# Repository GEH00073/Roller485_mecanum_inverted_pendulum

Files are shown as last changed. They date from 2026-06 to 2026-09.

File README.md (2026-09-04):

# Roller485 Mecanum Inverted Pendulum

Roller485を4台と80 mmメカナムホイールを使った、横一列配置の倒立振子ロボットです。本体側ファームウェアとAtom JoyStickコントローラー側ファームウェアを1つのリポジトリにまとめています。

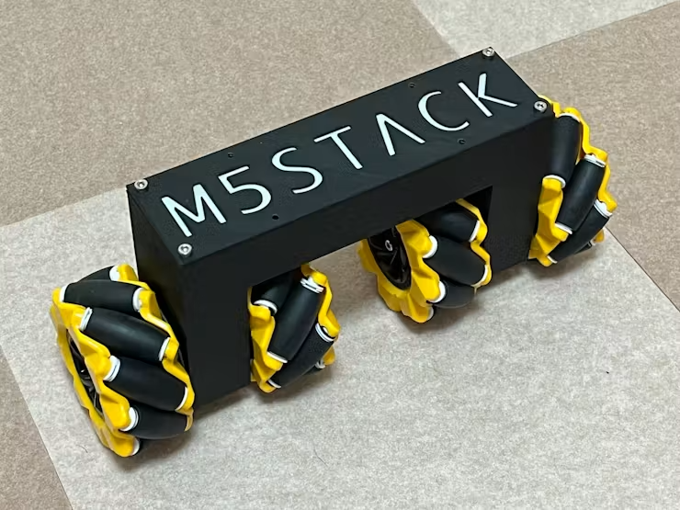
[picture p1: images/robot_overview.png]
完成したメカナムホイール倒立振子


[動作動画を見る](https://youtu.be/hXI0RIIv_HM)

## 構成

- 本体側: AtomS3R(またはAtomS3) + Roller485 x 4
- コントローラー側: Atom JoyStick
- 通信: ESP-NOW ch 3 ブロードキャスト
- 駆動電源: 7.2 V battery to PWR485
- 車輪: 80 mmメカナムホイール

## ディレクトリ構成

- `firmware/pendulum`: AtomS3R + Roller485 x 4 の本体側ファームウェア
- `firmware/controller`: Atom JoyStickコントローラー側ファームウェア
- `docs`: ESP-NOWパケット、配線、操作説明、安全注意の補足資料
- `images`: 写真や図を置くためのディレクトリ

## 起動から終了まで

1. コントローラーの電源を入れます。
2. 本体を安定した台に置き、4輪を床や台から浮かせます。
3. 倒立振子のバッテリーを接続します。
4. 4台のRoller485が1台ずつ順番に回転し、その後、ファームウェアの起動確認として4輪が同時に回転します。
5. `CHECK DONE` が表示され、車輪が停止するまで待ちます。
6. 車輪に触れない位置を持って本体を台から下ろし、床の上でできるだけ垂直に保持します。
7. 周囲の安全を確認して、コントローラーの右上ボタンを押し、倒立制御を開始します。
8. 終了時は本体が倒れないように保持してから右上ボタンを押します。
9. 車輪の停止を確認し、本体のバッテリーを必ず外します。
10. 最後にコントローラーの電源を切ります。

## コントローラー操作

| 操作動作 | 内容 |
| --- | --- |
| 右上ボタン | 倒立制御の開始／停止 |
| 左上ボタン | 通常モード／方向基準モードの切り替え |
| 右スティック上下 | 前進／後進 |
| 右スティック左右 | 左／右への平行移動 |
| 左スティック左右 | 左／右旋回 |
| 左スティック上下 | 前後ドリフトを抑えるための傾き補正 |

詳しい操作方法、方向基準モード、補正方法は [docs/controller.md](docs/controller.md) を参照してください。

## 安全上の注意

倒立振子は電源投入後や制御開始時に突然動く可能性があります。初回確認時は必ず車輪を浮かせ、周囲に十分な空間を確保してください。

- 初回確認時は必ず車輪を浮かせてテストしてください。
- 本体側は、有効なESP-NOWパケットを受信するまでモーターを起動しません。
- 本体ボタンだけでの単独起動は安全のため無効にしています。
- 転倒検出時とESP-NOW受信タイムアウト時はモーターを停止します。
- Roller485初期化に失敗した場合、制御タスクは開始されません。

## Roller485の配置とI2Cアドレス

4台のRoller485には、それぞれ異なるI2Cアドレスを設定します。

| 位置 | 説明 | I2Cアドレス |
| --- | --- | --- |
| LEFT | 左外側 | `0x64` |
| LEFT2 | 左内側 | `0x65` |
| RIGHT2 | 右内側 | `0x66` |
| RIGHT | 右外側 | `0x67` |

アドレスの変更方法とRoller485の電源仕様は、[M5Stack公式資料](https://docs.m5stack.com/ja/guide/motor_ctl/roller485/roller485)を参照してください。Roller485は1台ずつ接続して設定し、設定後はI2Cアドレスと取付位置が分かるラベルを貼ることを推奨します。

## ビルド方法

PlatformIOをインストールした環境で、それぞれのファームウェアディレクトリに移動してビルドします。リポジトリ直下ではなく、`firmware/pendulum` または `firmware/controller` をPlatformIOプロジェクトとして開いてください。

本体側ファームウェア:

```bash
cd firmware/pendulum
pio run
```

コントローラー側ファームウェア:

```bash
cd firmware/controller
pio run
```

初回ビルド時は、PlatformIOがボード定義や依存ライブラリを取得するため、インターネット接続が必要です。

## 機械加工・組立・3Dプリントについて

本機では、市販80 mmメカナムホイールの加工、3Dプリント部品、配線部品の現物合わせを行っています。3Dプリンター、材料、メカナムホイールの寸法公差、ネジ、コネクターなどにより、加工・組立条件は変わります。そのため、すべての環境に対応する詳細な組立手順やプリント条件を提示することは困難です。

STLとSTEPデータは [`3d_models`](3d_models) に収録しています。STEPデータも参考にし、使用する部品と製作環境に合わせて調整してください。

製作上の技術的な質問は、ほかの読者も回答を参照できるよう、原則として[GitHub Issues](https://github.com/GEH00073/Roller485_mecanum_inverted_pendulum/issues/new)を利用してください。質問には、使用部品の名称と型番、問題が発生している工程、配線または組立状態が分かる写真、表示されたメッセージや症状、使用したファームウェアのバージョンまたはコミットSHAを添えてください。

更新情報は [X @GEH00073](https://x.com/GEH00073) でも案内しますが、フォローやDMは必須ではありません。

## Roller485ライブラリについて

`unit_rolleri2c` は伊藤先生による修正版を使用しています。公式ライブラリより Roller485 との通信が速く、倒立振子のようにレスポンスが重要な用途では、この修正版を使用するのが適しています。

## OTA設定について

公開用の `platformio.ini` では、Wi-Fi SSIDとパスワードは空文字にしています。OTA書き込みを使う場合は、各自の環境に合わせて `WIFI_SSID`, `WIFI_PASSWORD`, 必要に応じて `OTA_PASSWORD` を設定してください。

## 関連ドキュメント

- `docs/espnow_packet.md`: ESP-NOWパケット仕様
- `docs/wiring.md`: AtomS3R、Roller485、電源まわりの配線
- `docs/controller.md`: Atom JoyStickコントローラーの操作説明
- `docs/safety.md`: 実験時の安全注意

## ライセンス

このリポジトリは複数ライセンスの集合であり、リポジトリ全体をMIT Licenseとするものではありません。個別ファイルの表示と[THIRD_PARTY_NOTICES.md](THIRD_PARTY_NOTICES.md)を優先してください。ライセンス原文は[LICENSES](LICENSES)にあります。

| 対象 | ライセンス／配布条件 | 備考 |
| --- | --- | --- |
| 伊藤恒平氏および片岡淳の独自コード（`firmware/*/src/main.cpp`、`firmware/controller/lib/ATOMS3Joy/`） | MIT | `LICENSES/MIT.txt`。伊藤氏の著作権を有する派生部分は、得たMIT条件の許諾に基づきます。 |
| M5Stack Unit Roller I2Cドライバーおよびbuzzer（`firmware/pendulum/src/unit_rolleri2c.*`、`firmware/controller/src/buzzer.*`） | MIT（M5Stack） | M5Stackのファイル内SPDX表示を保持しています。伊藤氏の高速化改変を含みます。 |
| MadgwickAHRS（`firmware/pendulum/src/MadgwickAHRS.*`） | GPL-3.0-only | Arduino版の上流が「GPL version 3」と明記しているためです。出典は第三者通知を参照してください。 |
| 本体側完成ファームウェア（`firmware/pendulum`） | GPL-3.0-only | MITの個別コードとGPL-3.0-onlyのMadgwickAHRSを結合してビルドするため、完成ファームウェアのソース／バイナリ配布にはGPL-3.0-onlyが適用されます。 |
| コントローラー側独自コード（`firmware/controller/src/`、`lib/ATOMS3Joy/`） | MIT | この行は独自コードだけを対象とします。 |
| コントローラー完成ファームウェア | MITの独自コード + M5Unified/M5GFX と各上流通知 | M5UnifiedはMIT。M5GFXはMITに加え、実際にリンクされるLovyanGFX・フォント・画像処理部の通知があります。GPL、LGPL、CC BY-SA 3.0 の旧M5AtomS3同梱物は含みません。詳細は`THIRD_PARTY_NOTICES.md`を参照してください。 |
| 文書、画像、3Dモデル（`docs/`、`images/`、`3d_models/`） | CC BY 4.0 | Copyright (c) 2026 Atsushi Kataoka。商用利用・再配布・改変を許可し、表示義務があります。`LICENSES/CC-BY-4.0.txt`を参照してください。 |

`LICENSE` はライセンス案内です。MITの原文だけをルートに置いて全ファイルへ適用されるように見せないため、この構成にしています。

```
Copyright (c) 2024 Kouhei Ito
Modifications Copyright (c) 2026 Atsushi Kataoka

Original code by Kouhei Ito. Modified by Atsushi Kataoka.
```

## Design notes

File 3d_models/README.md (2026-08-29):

# 3D model license

Copyright (c) 2026 Atsushi Kataoka

The 3D models in this directory, including STL and STEP files, are licensed
under Creative Commons Attribution 4.0 International (CC BY 4.0).  You may
share and adapt them, including for commercial purposes, if you provide
appropriate attribution and a link to the license.  See
`../LICENSES/CC-BY-4.0.txt`.

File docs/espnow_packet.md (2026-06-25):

# ESP-NOW パケット仕様

コントローラーは、チャンネル 3 で固定長 25 バイトの ESP-NOW ブロードキャストパケットを送信します。

```text
パケットサイズ: 25 バイト
byte 0-2: 宛先 MAC アドレス下位 3 バイト、またはブロードキャスト用の FF FF FF
byte 3-6: rudder / Psi、float
byte 7-10: throttle、float
byte 11-14: aileron / Phi、float
byte 15-18: elevator / Theta、float
byte 19: arm ボタン
byte 20: flip ボタン
byte 21: mode ボタン
byte 22: option ボタン
byte 23: proactive フラグ
byte 24: チェックサム、byte 0-23 の合計
```

現在公開しているファームウェアでは、byte 0-2 に `FF FF FF` を入れてブロードキャスト動作させています。本体側は、パケット長、宛先、チェックサムがすべて有効な場合だけ、最終受信時刻を更新します。

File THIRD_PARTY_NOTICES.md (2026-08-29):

# Third-party notices

This file records the licenses of third-party material included in this source
tree.  Retain this file and the referenced license texts when redistributing.

## MadgwickAHRS

`firmware/pendulum/src/MadgwickAHRS.cpp` and `.h` are derived from the Arduino
MadgwickAHRS library, itself an implementation of Sebastian Madgwick's AHRS
algorithm.  The upstream repository states GNU General Public License version
3: <https://github.com/arduino-libraries/MadgwickAHRS>.  This repository uses
the precise designation `GPL-3.0-only`; its text is
`LICENSES/GPL-3.0-only.txt`.  Atsushi Kataoka's modifications are identified in
the files.  The completed `firmware/pendulum` firmware must be distributed
under GPL-3.0-only.

## M5Stack Unit Roller I2C driver

`firmware/pendulum/src/unit_rolleri2c.cpp` and `.hpp` retain M5Stack Technology
CO LTD's `MIT` SPDX notices.  Upstream: <https://github.com/m5stack/M5Unit-Roller>.
The files include a performance-oriented I2C modification from the Kouhei Ito
derived project; do not remove M5Stack attribution.

`firmware/controller/src/buzzer.cpp` and `.h` also retain their M5Stack
Technology CO LTD MIT SPDX notices.

## Controller dependencies resolved by PlatformIO

The controller no longer vendors M5AtomS3.  Its `platformio.ini` resolves
M5Unified 0.2.21 and the transitive M5GFX 0.2.28 from the official M5Stack
PlatformIO packages.  The completed controller firmware therefore is not
described as “MIT only”: it contains the MIT-licensed project code together
with these dependencies and their applicable notices.

| Dependency actually linked in the clean build | Conditions | Upstream |
| --- | --- | --- |
| M5Unified 0.2.21 | MIT | <https://github.com/m5stack/M5Unified> |
| M5GFX 0.2.28 | M5GFX is MIT; the linked library also includes its documented LovyanGFX (FreeBSD), font, and image-code notices | <https://github.com/m5stack/M5GFX> |

The linker maps for both controller environments contain M5Unified and M5GFX,
and contain no M5AtomS3 or FastLED object.  M5GFX's upstream license inventory
lists the relevant component notices, including LovyanGFX (FreeBSD), Adafruit
GFX/GLCD fonts (2-clause BSD), Bodmer fonts (FreeBSD), IPA fonts (IPA Font
License), efont (3-clause BSD), TomThumb (3-clause BSD), and MIT-licensed image
utilities.  A distributor of a completed controller binary must retain the
notices from the exact M5Unified/M5GFX package versions used to build it.

The removed vendored M5AtomS3 library was the only repository material carrying
the former LGPL-2.1-or-later and CC BY-SA 3.0 notices.  Those licenses no
longer apply to this repository's controller source or its completed firmware.

## Documentation, images, and 3D models

`docs/`, `images/`, and `3d_models/` are Copyright (c) 2026 Atsushi Kataoka and
are licensed under Creative Commons Attribution 4.0 International (CC BY 4.0).
Commercial use, redistribution, and adaptation are permitted subject to the
attribution requirements.  The official license text is
`LICENSES/CC-BY-4.0.txt`; each directory contains a short notice.

## Project-origin code

For the MIT-licensed Kouhei Ito / Atsushi Kataoka code, retain:

```
Copyright (c) 2024 Kouhei Ito
Modifications Copyright (c) 2026 Atsushi Kataoka

Original code by Kouhei Ito. Modified by Atsushi Kataoka.
```

No license decision is made here for the repository's documentation, images,
or 3D models because their authorship and intended publication license are not
recorded in this tree.

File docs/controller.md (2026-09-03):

# コントローラー操作

Atom JoyStickコントローラーで倒立振子を操作します。起動時は通常モードです。

## 起動前の準備

1. コントローラーの電源を入れます。
2. 本体を安定した台に置き、4輪を床や台から浮かせます。
3. 周囲に人や障害物がなく、手、衣服、ケーブル、工具が車輪から離れていることを確認します。

## 起動手順

1. 本体のバッテリーを接続します。
2. 4台のRoller485が1台ずつ順番に回転することを確認します。
3. 続いて、ファームウェアの実装どおり4輪が同時に回転することを確認します。
4. `CHECK DONE` が表示され、車輪が停止するまで待ちます。
5. 本体を車輪や可動部から離れた位置で持ち、台から下ろして床の上でできるだけ垂直に保持します。
6. 周囲の安全を確認して右上ボタンを押し、倒立制御を開始します。

車輪が回転しない、回転方向が異常、異音がする、または引っ掛かりがある場合は、倒立制御を開始しないでください。本体のバッテリーを外して原因を確認してください。

## ボタンとスティックの割り当て

| 操作 | 動作 |
| --- | --- |
| 右上ボタン | 倒立制御を開始／停止します。 |
| 左上ボタン | 通常モードと方向基準モードを切り替えます。 |
| 右スティック上下 | 前進／後進します。 |
| 右スティック左右 | 左右へ平行移動します。 |
| 左スティック左右 | 左右旋回します。 |
| 左スティック上下 | 前後ドリフトを抑えるため、傾きの基準を補正します。 |

## 前後ドリフトの補正

前後へドリフトする場合は、左スティック上下で傾きの基準を補正します。左スティック上下は短く操作し、少しずつ調整してください。倒したままにすると補正が連続して変化するため注意してください。

## 移動方向モード

### 通常モード

起動時のモードです。本体の現在の向きを基準に、右スティックで前後・左右へ移動します。

### 方向基準モード

左上ボタンで方向基準モードへ切り替えると、その瞬間の本体の向きが基準方向として記憶されます。このモードでは本体が旋回しても、右スティックによる前後・左右移動は記憶した基準方向に対して行われます。

もう一度左上ボタンを押すと通常モードへ戻ります。基準方向を設定し直す場合は、一度通常モードへ戻し、希望する向きで再び左上ボタンを押してください。

## 終了手順

1. 本体が倒れないように保持します。
2. 右上ボタンを押して倒立制御を停止します。
3. 車輪が停止したことを確認し、本体のバッテリーを必ず外します。
4. バッテリーを外してからコントローラーの電源を切ります。

## 異常時の対応

異音、異常な回転、引っ掛かり、予期しない動作を感じた場合は、ただちに本体を安全に保持して倒立制御を停止してください。車輪の停止を確認してから本体のバッテリーを外し、原因を確認します。通電したまま無人で放置しないでください。

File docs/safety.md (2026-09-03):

# 安全上の注意

倒立振子は電源投入後や制御開始時に突然動く可能性があります。通電中はロボットの周囲に十分な空間を確保し、作業中は目を離さないでください。

## バッテリーと起動確認

- 損傷、変形、膨張、液漏れのあるバッテリーは使用しないでください。
- 本体を安定した台に置き、4輪を浮かせてからバッテリーを接続してください。
- 起動確認中は、手、衣服、ケーブル、工具を車輪へ近づけないでください。
- 起動確認が終了する前に、本体を台から持ち上げないでください。
- 回転しない車輪、異常な回転方向、異音、引っ掛かりがある場合は、倒立制御を開始せず、本体のバッテリーを外してください。

## 操作と終了

- 倒立制御を開始する前に、周囲の人と障害物を確認してください。
- 本体を持つ場合は、車輪や可動部から離れた位置を持ってください。
- 終了時は本体を保持してから右上ボタンで制御を停止してください。
- 車輪停止後に本体バッテリーを必ず外してください。
- バッテリーを外してからコントローラーを切ってください。
- 通電したまま無人で放置しないでください。

## ファームウェアの安全機能

- 電源投入直後に動き出さないよう、本体側は有効なESP-NOWパケットを受信するまでモーターを起動しません。
- ESP-NOWの受信タイムアウトを検出すると、モーターを停止します。
- 傾き角が転倒検出しきい値を超えると、モーターを停止します。
- Roller485の初期化に失敗した場合、制御タスクは開始されません。

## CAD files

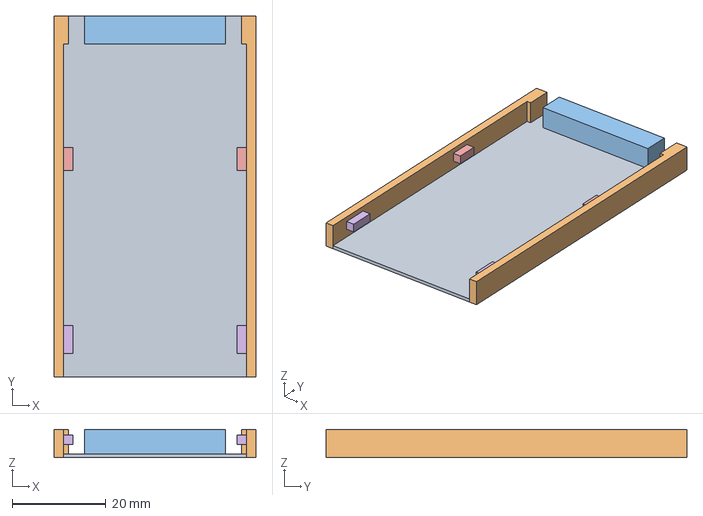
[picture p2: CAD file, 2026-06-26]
3d_models/STEP/NP-F550_batt_case.step
43.0 x 77.0 x 6.00 mm

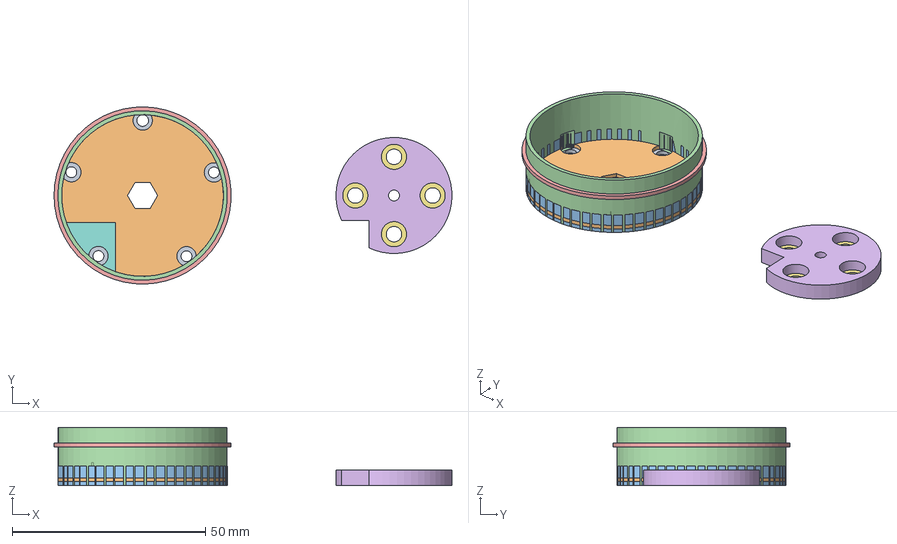
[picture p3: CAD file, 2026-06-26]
3d_models/STEP/80mm_mecanum_hub.step
102.9 x 45.8 x 15.0 mm

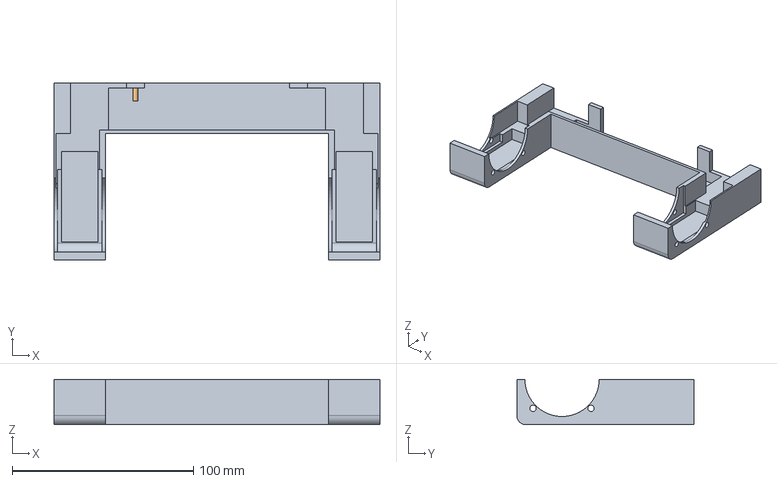
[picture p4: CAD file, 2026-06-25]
3d_models/STEP/roller485_mecanum_80mm_frame.step
180.0 x 98.0 x 25.0 mm

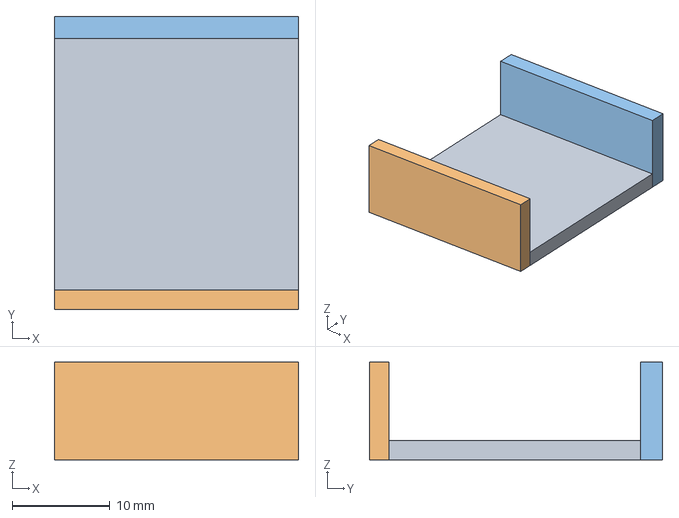
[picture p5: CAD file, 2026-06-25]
3d_models/STEP/atom_base.step
25.0 x 30.0 x 10.0 mm

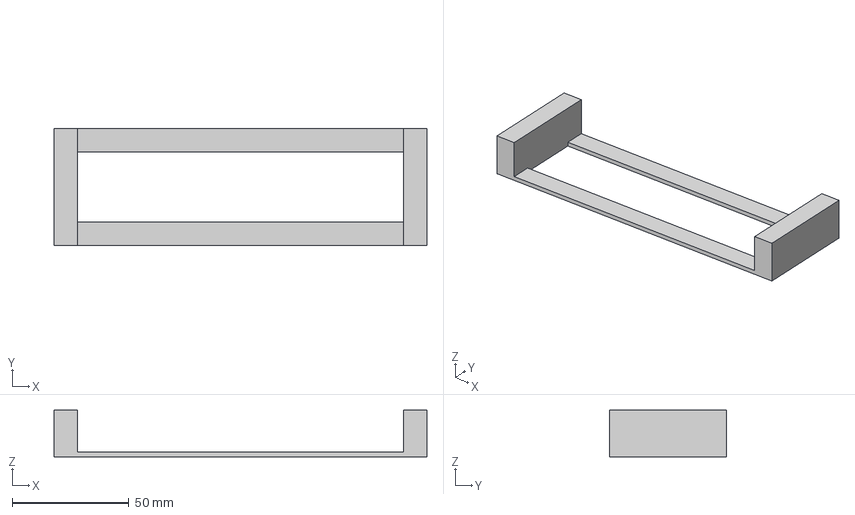
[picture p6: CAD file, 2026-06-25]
3d_models/STEP/80mm_mecanum_stand.step
160.0 x 50.0 x 20.0 mm

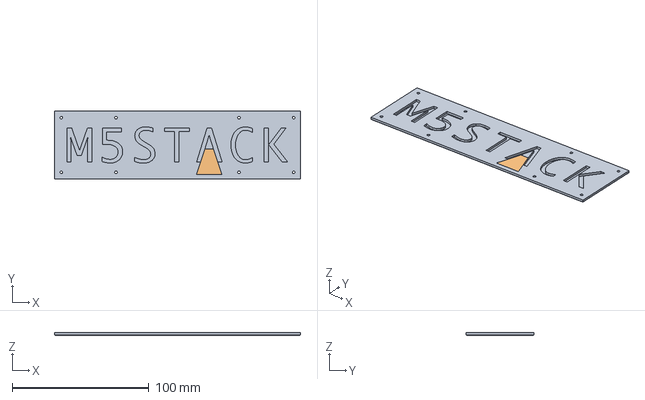
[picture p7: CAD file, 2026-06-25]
3d_models/STEP/80mm_mecanu_top_cover.step
180.0 x 50.0 x 2.00 mm

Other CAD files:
3d_models/STL/80mm_mecanu_top_cover.stl
3d_models/STL/80mm_mecanum_hub.stl
3d_models/STL/80mm_mecanum_stand.stl
3d_models/STL/NP-F550_batt_case.stl
3d_models/STL/atom_base.stl
3d_models/STL/roller485_mecanum_80mm_frame.stl

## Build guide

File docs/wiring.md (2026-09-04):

# 配線

トランジスタ技術の記事の接続図を前提にした配線です。配線作業中は必ずバッテリーを外してください。

## I2C信号

ATOMS3RまたはAtomS3のPORT.Aを使用します。G7、G8、GNDは4台のRoller485で共通にし、4台は同じI2Cバスを共有します。各Roller485はI2Cアドレスで識別します。

## ATOMS3R/AtomS3への5 V給電

ATOMS3R/AtomS3への5 Vは、4台のRoller485のうち任意の1台だけから供給します。複数のRoller485の5 V出力を並列接続しないでください。4台で共通にするのはG7、G8、GNDです。ATOMS3R/AtomS3へ5 Vを供給しない残り3台の5 V線は接続しません。

市販のGrove 4線ケーブルをそのまま4台分並列接続すると、5 V線まで並列接続される可能性があります。必要な信号線だけを接続できる自作ケーブルまたは分岐配線を使用してください。

## 7.2 V駆動電源

7.2 Vバッテリーを4台のRoller485のPWR485入力へ分配します。バッテリーのプラスを各PWR485電源入力へ、マイナスを各Roller485のGNDへ接続してください。ATOMS3R/AtomS3、Roller485、バッテリーのGNDは共通にします。

電源の極性を接続前に確認してください。逆接、短絡、配線抜けがある状態で電源を入れないでください。

Roller485の電源仕様とI2Cアドレス設定は、[M5Stack公式資料](https://docs.m5stack.com/ja/guide/motor_ctl/roller485/roller485)を参照してください。

## Roller485の配置とI2Cアドレス

| 位置 | 説明 | I2Cアドレス |
| --- | --- | --- |
| LEFT | 左外側 | `0x64` |
| LEFT2 | 左内側 | `0x65` |
| RIGHT2 | 右内側 | `0x66` |
| RIGHT | 右外側 | `0x67` |

アドレスの設定方法は、上記のM5Stack公式資料を参照してください。

## コントローラーとの通信

Atom JoyStick コントローラーと本体側 AtomS3R/AtomS3 は、ESP-NOW のチャンネル 3 で無線接続します。

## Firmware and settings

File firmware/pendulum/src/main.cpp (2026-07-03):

// SPDX-FileCopyrightText: 2024 Kouhei Ito
// SPDX-FileCopyrightText: 2026 Atsushi Kataoka
// SPDX-License-Identifier: MIT
//
// Experimental firmware for a mecanum-wheel inverted pendulum using four Roller485 units.
// The 5 ms control loop updates the IMU, estimates attitude, runs balance control, and
// distributes current commands to the four wheels.
// For first bring-up, always test with the wheels lifted off the floor.
// Motors are stopped on ESP-NOW receiver timeout or fall detection.
// Motors do not start until a valid ESP-NOW packet is received; local button-only
// startup is intentionally disabled for safety.

#include <Arduino.h>
#include <ArduinoOTA.h>
#include "unit_rolleri2c.hpp"
#include <M5Unified.h>
#include <MadgwickAHRS.h>
#include <WiFi.h>
#include <esp_now.h>
#include <esp_wifi.h>
#include <cstring>

// Roller layout reference:
//   LEFT   = left outer,  addr 0x64
//   LEFT2  = left inner,  addr 0x65
//   RIGHT2 = right inner, addr 0x66
//   RIGHT  = right outer, addr 0x67
UnitRollerI2C RollerI2C_RIGHT;  // Create a UNIT_ROLLERI2C object
UnitRollerI2C RollerI2C_RIGHT2;
UnitRollerI2C RollerI2C_LEFT;
UnitRollerI2C RollerI2C_LEFT2;
//I2Cドライバの多重初期化を防ぐためのフラグ
bool UnitRollerI2C::initialized = false;

float Pitch_ahrs, Roll_ahrs, Yaw_ahrs, Roll_bias, Roll;
float Gyro_x, Gyro_y, Gyro_z;
float Acc_x, Acc_y, Acc_z;
int32_t Imu_time,_Imu_time, Imu_dtime;
int32_t Current_ref_r, Current_ref_l;
int32_t Current_ref_r2, Current_ref_l2;
int32_t Current_r, Current_l;
int32_t Current_r2, Current_l2;
int32_t Pos_r, Pos_l, Pos_bias_r, Pos_bias_l;
int32_t Pos_r2, Pos_l2, Pos_bias_r2, Pos_bias_l2;
int32_t Speed_r, Speed_l;
int32_t Speed_r2, Speed_l2;
int32_t Voltage_r,Voltage_l;
int32_t Voltage_r2,Voltage_l2;
int32_t St, _St, Et, Dt;
float f1,f2,f3,f4;
float k1;
float U0, U_yaw, U_v, U_l;
uint8_t Start_flag = 0;
bool mode_flag = false;
float yaw, angle, start_yaw, target_yaw, diff;

#ifndef WIFI_SSID
#define WIFI_SSID ""
#endif

#ifndef WIFI_PASSWORD
#define WIFI_PASSWORD ""
#endif

#ifndef OTA_HOSTNAME
#define OTA_HOSTNAME "roller485-pendulum"
#endif

#ifndef OTA_PASSWORD
#define OTA_PASSWORD ""
#endif

namespace {
constexpr uint32_t kStartupOtaWindowMs = 5000;
constexpr int32_t kBatteryDetectVinRaw = 600;  // getVin() is displayed as raw / 100.0 V.
constexpr int32_t kStartupCheckCurrent = 10000;
constexpr uint32_t kStartupCheckPulseMs = 450;
constexpr uint32_t kStartupCheckSettleMs = 250;
constexpr uint32_t kControlPeriodMs = 5;
constexpr uint32_t kRcTimeoutMs = 300;
constexpr float kFallStopAngleDeg = 70.0f;
constexpr int32_t kCurrentLimit = 120000;
constexpr float kStickDeadband = 0.05f;
constexpr float kRollAngleGain = 7000.0f;
constexpr float kGyroGain = 250.0f;
constexpr float kWheelSpeedGain = -5.0f;
constexpr float kYawRateGain = 300.0f;
constexpr float kForwardGain = 150000.0f;
constexpr float kLateralGain = 100000.0f;
constexpr float kLateralYawCompensationGain = 67000.0f;
constexpr float kYawReferenceScale = -360.0f / 2.0f;
constexpr float kDriftTargetYawStep = 1.0f;
constexpr uint32_t kUiToggleDebounceMs = 500;
constexpr uint32_t kRollBiasAdjustIntervalMs = 100;
constexpr float kRollBiasStepDeg = 0.2f;
constexpr uint8_t kEspNowChannel = 3;
constexpr uint8_t kBroadcastAddr[6] = {0xff, 0xff, 0xff, 0xff, 0xff, 0xff};
bool startupOtaStarted = false;
bool startupOtaInProgress = false;
volatile uint8_t MyMacAddr[6];
volatile uint8_t Rc_err_flag = 0;
volatile uint8_t Recv_MAC[3];
volatile uint16_t Connect_flag = 0;
volatile float Stick[16];
volatile uint32_t last_rc_rx_ms = 0;
portMUX_TYPE stickMux = portMUX_INITIALIZER_UNLOCKED;
esp_now_peer_info_t peerInfo;

enum StickIndex : uint8_t {
    RUDDER = 0,
    ELEVATOR = 1,
    THROTTLE = 2,
    AILERON = 3,
    LOG = 4,
    BUTTON_ARM = 9,
    BUTTON_FLIP = 10,
    CONTROLMODE = 11,
    ALTCONTROLMODE = 12,
};

void copyStickSnapshot(float (&snapshot)[16])
{
    portENTER_CRITICAL(&stickMux);
    for (uint8_t i = 0; i < 16; i++) {
        snapshot[i] = Stick[i];
    }
    portEXIT_CRITICAL(&stickMux);
}

uint32_t getLastRcRxMs()
{
    portENTER_CRITICAL(&stickMux);
    const uint32_t lastRxMs = last_rc_rx_ms;
    portEXIT_CRITICAL(&stickMux);
    return lastRxMs;
}

float readFloatFromPacket(const uint8_t* recvData, uint8_t offset)
{
    float value = 0.0f;
    memcpy(&value, &recvData[offset], sizeof(value));
    return value;
}

int32_t clampCurrent(int32_t current)
{
    if (current > kCurrentLimit) {
        return kCurrentLimit;
    }
    if (current < -kCurrentLimit) {
        return -kCurrentLimit;
    }
    return current;
}

struct StartupRollerCheckStep {
    const char* label;
    uint8_t addr;
    UnitRollerI2C* roller;
    int8_t logicalSign;
};

bool startupOtaIsConfigured()
{
    return strlen(WIFI_SSID) > 0;
}

void onEspNowRecv(const uint8_t* macAddr, const uint8_t* recvData, int dataLen)
{
    (void)macAddr;
    Connect_flag = 0;

    if (dataLen < 25) {
        Rc_err_flag = 1;
        return;
    }

    Recv_MAC[0] = recvData[0];
    Recv_MAC[1] = recvData[1];
    Recv_MAC[2] = recvData[2];

    const bool addressedToMe =
        (recvData[0] == MyMacAddr[3]) && (recvData[1] == MyMacAddr[4]) && (recvData[2] == MyMacAddr[5]);
    const bool addressedToBroadcast =
        (recvData[0] == 0xff) && (recvData[1] == 0xff) && (recvData[2] == 0xff);

    if (!addressedToMe && !addressedToBroadcast) {
        Rc_err_flag = 1;
        return;
    }

    uint8_t checkSum = 0;
    for (uint8_t i = 0; i < 24; i++) {
        checkSum = checkSum + recvData[i];
    }
    if (checkSum != recvData[24]) {
        Rc_err_flag = 1;
        return;
    }

    Rc_err_flag = 0;

    const float rudder = readFloatFromPacket(recvData, 3);
    const float throttle = readFloatFromPacket(recvData, 7);
    const float aileron = readFloatFromPacket(recvData, 11);
    const float elevator = readFloatFromPacket(recvData, 15);
    const uint32_t nowMs = millis();

    portENTER_CRITICAL(&stickMux);
    Stick[RUDDER] = rudder;
    Stick[THROTTLE] = throttle;
    Stick[AILERON] = aileron;
    Stick[ELEVATOR] = elevator;
    Stick[BUTTON_ARM] = recvData[19];
    Stick[BUTTON_FLIP] = recvData[20];
    Stick[CONTROLMODE] = recvData[21];
    Stick[ALTCONTROLMODE] = recvData[22];
    Stick[LOG] = 0.0f;
    last_rc_rx_ms = nowMs;
    portEXIT_CRITICAL(&stickMux);
}

void rcInit()
{
    portENTER_CRITICAL(&stickMux);
    for (uint8_t i = 0; i < 16; i++) {
        Stick[i] = 0.0f;
    }
    last_rc_rx_ms = 0;
    portEXIT_CRITICAL(&stickMux);

    WiFi.mode(WIFI_STA);
    WiFi.disconnect();

    WiFi.macAddress((uint8_t*)MyMacAddr);
    Serial.printf("MAC ADDRESS: %02X:%02X:%02X:%02X:%02X:%02X\r\n",
                  MyMacAddr[0], MyMacAddr[1], MyMacAddr[2],
                  MyMacAddr[3], MyMacAddr[4], MyMacAddr[5]);

    if (esp_now_init() != ESP_OK) {
        Serial.println("ESPNow Init Failed");
        ESP.restart();
    }
    Serial.println("ESPNow Init Success");

    esp_wifi_set_channel(kEspNowChannel, WIFI_SECOND_CHAN_NONE);

    memset(&peerInfo, 0, sizeof(peerInfo));
    memcpy(peerInfo.peer_addr, kBroadcastAddr, 6);
    peerInfo.channel = kEspNowChannel;
    peerInfo.encrypt = false;
    if (esp_now_add_peer(&peerInfo) != ESP_OK) {
        Serial.println("Failed to add broadcast peer");
        return;
    }

    esp_now_register_recv_cb(onEspNowRecv);
    Serial.println("ESP-NOW Broadcast Ready.");
}

void setupStartupOTA()
{
    if (startupOtaStarted || !startupOtaIsConfigured()) {
        return;
    }

    ArduinoOTA.setHostname(OTA_HOSTNAME);
    if (strlen(OTA_PASSWORD) > 0) {
        ArduinoOTA.setPassword(OTA_PASSWORD);
    }

    ArduinoOTA
        .onStart([]() {
            startupOtaInProgress = true;
            Start_flag = 0;
            Serial.println("OTA update started during startup window.");
            M5.Display.clear(TFT_BLUE);
            M5.Display.setCursor(0, 10);
            M5.Display.print("OTA");
        })
        .onEnd([]() {
            Serial.println("\nOTA update finished. Restarting.");
            delay(500);
            ESP.restart();
        })
        .onProgress([](unsigned int progress, unsigned int total) {
            const unsigned int percent = total == 0 ? 0 : (progress * 100) / total;
            static unsigned int lastPercent = 101;
            if (percent != lastPercent) {
                lastPercent = percent;
                Serial.printf("OTA progress: %u%%\r", percent);
            }
        })
        .onError([](ota_error_t error) {
            startupOtaInProgress = false;
            Serial.printf("OTA error[%u]\n", error);
        });

    ArduinoOTA.begin();
    startupOtaStarted = true;
    Serial.printf("Startup OTA ready: %s.local IP: %s\n", OTA_HOSTNAME, WiFi.localIP().toString().c_str());
}

void updateImuDuringStartupOTA()
{
    M5.Imu.update();
    auto imudata = M5.Imu.getImuData();
    Gyro_x = imudata.gyro.x;
    Gyro_y = imudata.gyro.y;
    Gyro_z = imudata.gyro.z;
    Acc_x = imudata.accel.x;
    Acc_y = imudata.accel.y;
    Acc_z = imudata.accel.z;
    MadgwickAHRSupdateIMU(Gyro_x * DEG_TO_RAD, Gyro_y * DEG_TO_RAD, Gyro_z * DEG_TO_RAD, Acc_x, Acc_y, Acc_z, &Pitch_ahrs, &Roll_ahrs, &Yaw_ahrs);
    Roll = 0.3f * Roll + 0.7f * Roll_ahrs;
}

void serviceStartupOTAWindow()
{
    if (!startupOtaIsConfigured()) {
        return;
    }

    const uint32_t windowStartMs = millis();
    WiFi.mode(WIFI_STA);
    WiFi.begin(WIFI_SSID, WIFI_PASSWORD);
    Serial.printf("Startup OTA + IMU calibration window: connecting WiFi %s\n", WIFI_SSID);
    M5.Display.clear(TFT_BLUE);
    M5.Display.setCursor(0, 10);
    M5.Display.print("OTA+IMU");

    while ((millis() - windowStartMs < kStartupOtaWindowMs) || startupOtaInProgress) {
        updateImuDuringStartupOTA();
        if (WiFi.status() == WL_CONNECTED) {
            setupStartupOTA();
            ArduinoOTA.handle();
        }
        M5.update();
        delay(10);
    }

    if (startupOtaStarted) {
        ArduinoOTA.end();
        startupOtaStarted = false;
    }
    WiFi.disconnect(false, true);
    WiFi.mode(WIFI_OFF);
    M5.Display.clear(TFT_BLACK);
    Serial.println("Startup OTA window closed. Continuing normal startup.");
}

void stopAllRollers()
{
    Current_ref_r = 0;
    Current_ref_l = 0;
    Current_ref_r2 = 0;
    Current_ref_l2 = 0;
    RollerI2C_RIGHT.setCurrent(0);
    RollerI2C_LEFT.setCurrent(0);
    RollerI2C_RIGHT2.setCurrent(0);
    RollerI2C_LEFT2.setCurrent(0);
}

void stopInitializedRollers(bool rightOk, bool leftOk, bool right2Ok, bool left2Ok)
{
    Current_ref_r = 0;
    Current_ref_l = 0;
    Current_ref_r2 = 0;
    Current_ref_l2 = 0;
    if (rightOk) {
        RollerI2C_RIGHT.setCurrent(0);
    }
    if (leftOk) {
        RollerI2C_LEFT.setCurrent(0);
    }
    if (right2Ok) {
        RollerI2C_RIGHT2.setCurrent(0);
    }
    if (left2Ok) {
        RollerI2C_LEFT2.setCurrent(0);
    }
}

void waitWithM5Update(uint32_t waitMs)
{
    const uint32_t startMs = millis();
    while (millis() - startMs < waitMs) {
        M5.update();
        delay(10);
    }
}

int32_t readStartupBatteryVinRaw()
{
    int32_t vin = RollerI2C_RIGHT.getVin();
    vin = max(vin, RollerI2C_LEFT.getVin());
    vin = max(vin, RollerI2C_RIGHT2.getVin());
    vin = max(vin, RollerI2C_LEFT2.getVin());
    return vin;
}

void applyLogicalCurrent(const StartupRollerCheckStep& step, int32_t current)
{
    step.roller->setCurrent(step.logicalSign * current);
}

void showStartupCheckScreen(const char* label, uint8_t addr, int32_t vinRaw)
{
    M5.Display.clear(TFT_BLACK);
    M5.Display.setCursor(0, 4);
    M5.Display.printf("CHK %s\n", label);
    M5.Display.printf("addr 0x%02X\n", addr);
    M5.Display.printf("Vin %4.1fV\n", (float)vinRaw / 100.0f);
}

void runStartupRollerCheckMode()
{
    const int32_t vinRaw = readStartupBatteryVinRaw();
    if (vinRaw < kBatteryDetectVinRaw) {
        Serial.printf("Startup roller check skipped. Vin %.2f V\n", (float)vinRaw / 100.0f);
        return;
    }

    const StartupRollerCheckStep steps[] = {
        {"LEFT",   0x64, &RollerI2C_LEFT,   -1},
        {"LEFT2",  0x65, &RollerI2C_LEFT2,   1},
        {"RIGHT2", 0x66, &RollerI2C_RIGHT2, -1},
        {"RIGHT",  0x67, &RollerI2C_RIGHT,   1},
    };

    Serial.printf("Startup roller check started. Vin %.2f V\n", (float)vinRaw / 100.0f);
    M5.Display.clear(TFT_BLUE);
    M5.Display.setCursor(0, 4);
    M5.Display.println("ROLLER CHECK");
    M5.Display.printf("Vin %4.1fV\n", (float)vinRaw / 100.0f);
    waitWithM5Update(800);

    stopAllRollers();
    for (const auto& step : steps) {
        showStartupCheckScreen(step.label, step.addr, vinRaw);
        Serial.printf("Check %s addr=0x%02X logical current=%ld raw current=%ld\n",
                      step.label,
                      step.addr,
                      (long)kStartupCheckCurrent,
                      (long)(step.logicalSign * kStartupCheckCurrent));
        applyLogicalCurrent(step, kStartupCheckCurrent);
        waitWithM5Update(kStartupCheckPulseMs);
        stopAllRollers();
        waitWithM5Update(kStartupCheckSettleMs);
    }

    M5.Display.clear(TFT_BLUE);
    M5.Display.setCursor(0, 4);
    M5.Display.println("CHK FWD");
    M5.Display.println("all wheels");
    Serial.println("Check all wheels logical forward");
    for (const auto& step : steps) {
        applyLogicalCurrent(step, kStartupCheckCurrent);
    }
    waitWithM5Update(kStartupCheckPulseMs);
    stopAllRollers();
    waitWithM5Update(kStartupCheckSettleMs);

    M5.Display.clear(TFT_BLACK);
    M5.Display.setCursor(0, 4);
    M5.Display.println("CHECK DONE");
    Serial.println("Startup roller check finished.");
    waitWithM5Update(500);
    M5.Display.clear(TFT_BLACK);
}
}  // namespace

void uiTask(void *pvParameters) {
    uint32_t lastStartToggleMs = 0;
    uint32_t lastModeToggleMs = 0;
    uint32_t lastRollBiasAdjustMs = 0;

    while (true) {
        vTaskDelay(pdMS_TO_TICKS(50));
        float stick[16];
        copyStickSnapshot(stick);
        const uint32_t nowMs = millis();

        M5.Display.setCursor(0, 10);
        M5.Display.printf("roll %4.1f\n", Roll);
        M5.Display.printf("V    %4.1f\n", (float)Voltage_r/100.0);
        M5.Display.printf("dt   %4.1f\n", (float)Dt/1.0e3);
        M5.Display.printf("yaw  %4.1f\n", (float)target_yaw);
        M5.Display.printf("diff %4.1f\n", (float)diff);

        M5.update();
        if((stick[CONTROLMODE] > 0.9 || M5.BtnA.wasPressed()) &&
           (nowMs - lastStartToggleMs >= kUiToggleDebounceMs)){ //右ボタンでトグル
            //Star_flagをトグル 
            Start_flag = !Start_flag;
            Roll_bias = Roll;
            Pos_bias_r = Pos_r;
            Pos_bias_l = Pos_l;
            start_yaw = -Yaw_ahrs;
            target_yaw = 0; 
            lastStartToggleMs = nowMs;
        }

        f4 = kWheelSpeedGain;

        if(stick[ALTCONTROLMODE] > 0.9 &&
           (nowMs - lastModeToggleMs >= kUiToggleDebounceMs)){ //左ボタンでトグル
            mode_flag = !mode_flag; //true = drift mode, false = normal mode
            if(mode_flag == true){
                start_yaw = -Yaw_ahrs;
                target_yaw = 0; 
            }
            lastModeToggleMs = nowMs;
        }

        if(nowMs - lastRollBiasAdjustMs >= kRollBiasAdjustIntervalMs) {
            if(stick[THROTTLE] > 0.9){ //THROTTLE上でRoll_bias UP
                Roll_bias = Roll_bias - kRollBiasStepDeg;
                lastRollBiasAdjustMs = nowMs;
            }
            else if(stick[THROTTLE] < -0.9){ //THROTTLE下でRoll_bias Down
                Roll_bias = Roll_bias + kRollBiasStepDeg;
                lastRollBiasAdjustMs = nowMs;
            }
        }

        if(Roll < -kFallStopAngleDeg or Roll > kFallStopAngleDeg){ //転倒したらOFF
            Start_flag = 0;
        }

    }
}

void controlTask(void *pvParameters) {
    TickType_t xLastWakeTime;
    const TickType_t xFrequency = pdMS_TO_TICKS(kControlPeriodMs); // 5ms の周期

    // 初期化
    xLastWakeTime = xTaskGetTickCount();

    while (true) {
        // 次の周期まで待機
        vTaskDelayUntil(&xLastWakeTime, xFrequency);
        _St = St;
        St = micros();
        float stick[16];
        copyStickSnapshot(stick);
        const uint32_t lastRcRxMs = getLastRcRxMs();
        const bool rcTimedOut = (lastRcRxMs == 0) || (millis() - lastRcRxMs > kRcTimeoutMs);

        // TODO: If M5Unified exposes a reliable IMU update failure status for this board,
        // stopAllRollers() should be called on failure.
        M5.Imu.update();
        auto imudata = M5.Imu.getImuData();
        Gyro_x = imudata.gyro.x;
        Gyro_y = imudata.gyro.y;
        Gyro_z = imudata.gyro.z;
        Acc_x = imudata.accel.x;
        Acc_y = imudata.accel.y;
        Acc_z = imudata.accel.z;
        
        MadgwickAHRSupdateIMU(Gyro_x * DEG_TO_RAD, Gyro_y * DEG_TO_RAD, Gyro_z * DEG_TO_RAD, Acc_x, Acc_y, Acc_z, &Pitch_ahrs, &Roll_ahrs, &Yaw_ahrs);
        k1 = 0.3;
        Roll = k1*Roll +(1-k1)*Roll_ahrs;

        Current_r =  RollerI2C_RIGHT.getCurrentReadback();
        Current_r2 =  -RollerI2C_RIGHT2.getCurrentReadback();
        Current_l = -RollerI2C_LEFT.getCurrentReadback();
        Current_l2 = RollerI2C_LEFT2.getCurrentReadback();
        Pos_r =  RollerI2C_RIGHT.getPosReadback();
        Pos_r2 =  -RollerI2C_RIGHT2.getPosReadback();
        Pos_l = -RollerI2C_LEFT.getPosReadback();
        Pos_l2 = RollerI2C_LEFT2.getPosReadback();
        Speed_r =  RollerI2C_RIGHT.getSpeedReadback();
        Speed_r2 =  -RollerI2C_RIGHT2.getSpeedReadback();
        Speed_l = -RollerI2C_LEFT.getSpeedReadback();
        Speed_l2 = RollerI2C_LEFT2.getSpeedReadback();
        Voltage_r = RollerI2C_RIGHT.getVin();
        //Voltage_l = RollerI2C_LEFT.getVin();
        // TODO: UnitRollerI2C::getErrorCode() exists, but the exact error semantics are
        // not documented here. Add stopAllRollers() when a reliable fault condition is defined.

        if (rcTimedOut) {
            Start_flag = 0;
        }

        // current control
        if(Start_flag==1){
            f1 = kRollAngleGain; //振子の角度に比例して電流を制御
            f2 = kGyroGain; //振子の角速度に比例して電流を制御
            float a = stick[RUDDER];
            float b = -stick[ELEVATOR];
            float c = stick[AILERON];
            if( a > -kStickDeadband and a < kStickDeadband){a = 0.0;} //dead band
            if( b > -kStickDeadband and b < kStickDeadband){b = 0.0;} //dead band
            if( c > -kStickDeadband and c < kStickDeadband){c = 0.0;} //dead band

            if(mode_flag == true){ //drift mode
                float angle_rad = target_yaw * PI / 180.0;
                // 回転計算
                float x1 = c * cos(angle_rad) - b * sin(angle_rad);
                float y1 = c * sin(angle_rad) + b * cos(angle_rad);
                c = x1 / 2.0;
                b = y1;

                target_yaw += a * kDriftTargetYawStep;
                if(target_yaw > 360) target_yaw -= 360;
                if(target_yaw < 0) target_yaw += 360;
                diff = -Yaw_ahrs - start_yaw - target_yaw;
                if(diff > 180) diff -= 360;
                if(diff < -180) diff += 360;
                a = -diff / 10;
            }

            float yaw_ref = kYawReferenceScale * a; 
            float yaw_err = yaw_ref - Gyro_z;
            U_yaw = yaw_err * kYawRateGain; //回転
            U_v = -b * kForwardGain; //前後移動 ELEVATOR
            U_l = c * kLateralGain; //左右移動 AILERON
            float C_yaw = -c * kLateralYawCompensationGain; //左右移動時の回転モーメント補正
            //State feedback control
            U0 = (-f1 * (Roll - Roll_bias) 
                 - f2 * Gyro_x 
                 - f3 * (float)(Pos_r - Pos_bias_r + Pos_l - Pos_bias_l)/2.0 
                 - f4 * (Speed_r + Speed_l + Speed_r2 + Speed_l2)/4.0 );

            Current_ref_r  = (int32_t)(U0 + U_v + U_yaw + U_l + C_yaw);
            Current_ref_r2 = (int32_t)(U0 + U_v + U_yaw - U_l); 
            Current_ref_l  = (int32_t)(U0 + U_v - U_yaw - U_l - C_yaw);
            Current_ref_l2 = (int32_t)(U0 + U_v - U_yaw + U_l);

            //limit current
            Current_ref_r = clampCurrent(Current_ref_r);
            Current_ref_l = clampCurrent(Current_ref_l);
            Current_ref_r2 = clampCurrent(Current_ref_r2);
            Current_ref_l2 = clampCurrent(Current_ref_l2);

            RollerI2C_RIGHT.setCurrent(Current_ref_r);
            RollerI2C_RIGHT2.setCurrent(-Current_ref_r2);
            RollerI2C_LEFT.setCurrent(-Current_ref_l);
            RollerI2C_LEFT2.setCurrent(Current_ref_l2);
        }
        else{
            stopAllRollers();
        }
        Et = micros();
        Dt = Et - St;

    }
}
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
void loop() {
    // FreeRTOSを使用する場合、loop関数は空にします
    delay(1);
}

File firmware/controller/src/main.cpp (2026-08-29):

// SPDX-FileCopyrightText: 2024 Kouhei Ito
// SPDX-FileCopyrightText: 2026 Atsushi Kataoka
// SPDX-License-Identifier: MIT
//
// ESP-NOW joystick transmitter for the Roller485 mecanum inverted pendulum.
// Sends a 25-byte broadcast packet on channel 3; pairing is intentionally skipped.
// The receiver does not start the motors until it receives a valid packet.
// For first bring-up, always test the receiver with the wheels lifted off the floor.

#include <Arduino.h>
#include <ArduinoOTA.h>
#include <M5Unified.h>
#include <WiFi.h>
#include <esp_now.h>
#include <esp_wifi.h>
#include <cstring>
#include <atoms3joy.h>
#include "buzzer.h"

#define CHANNEL 3

#define ANGLECONTROL 0
#define RATECONTROL 1
#define ANGLECONTROL_W_LOG 2
#define RATECONTROL_W_LOG 3
#define ALT_CONTROL_MODE 4
#define NOT_ALT_CONTROL_MODE 5
#define RESO10BIT (4096)

esp_now_peer_info_t peerInfo;

float Throttle;
float Phi, Theta, Psi;
uint16_t Phi_bias = 2048;
uint16_t Theta_bias = 2048;
uint16_t Psi_bias = 2048;
uint16_t Throttle_bias = 2048;
short xstick = 0;
short ystick = 0;
uint8_t Mode = ANGLECONTROL;
uint8_t AltMode = NOT_ALT_CONTROL_MODE;
volatile uint8_t Loop_flag = 0;
float Timer = 0.0;
float dTime = 0.01;
uint8_t Timer_state = 0;
uint8_t StickMode = 2;
uint32_t espnow_version;
volatile uint8_t proactive_flag = 0;
unsigned long stime, etime, dtime, ltime;
uint8_t axp_cnt = 0;
uint8_t senddata[25];
uint8_t disp_counter = 0;

uint8_t BroadcastAddr[6] = {0xFF, 0xFF, 0xFF, 0xFF, 0xFF, 0xFF};
volatile uint8_t Channel = CHANNEL;


#ifndef WIFI_SSID
#define WIFI_SSID ""
#endif

#ifndef WIFI_PASSWORD
#define WIFI_PASSWORD ""
#endif

#ifndef OTA_HOSTNAME
#define OTA_HOSTNAME "roller485-joy"
#endif

#ifndef OTA_PASSWORD
#define OTA_PASSWORD ""
#endif

namespace {
constexpr uint32_t kOtaButtonHoldMs = 2000;
constexpr uint32_t kOtaWifiRetryIntervalMs = 10000;
constexpr size_t kEspNowPacketSize = 25;
constexpr uint8_t kEspNowChecksumOffset = 24;
constexpr uint8_t kPacketDestinationOffset = 0;
constexpr uint8_t kPsiOffset = 3;
constexpr uint8_t kThrottleOffset = 7;
constexpr uint8_t kPhiOffset = 11;
constexpr uint8_t kThetaOffset = 15;
bool otaModeEnabled = false;
bool otaStarted = false;
uint32_t lastOtaWifiAttemptMs = 0;
uint32_t otaButtonHoldStartMs = 0;

void writeFloatToPacket(uint8_t* packet, uint8_t offset, float value)
{
  memcpy(&packet[offset], &value, sizeof(value));
}

bool otaIsConfigured()
{
  return strlen(WIFI_SSID) > 0;
}

void setupOTA()
{
  if (otaStarted || !otaIsConfigured()) {
    return;
  }

  ArduinoOTA.setHostname(OTA_HOSTNAME);
  if (strlen(OTA_PASSWORD) > 0) {
    ArduinoOTA.setPassword(OTA_PASSWORD);
  }

  ArduinoOTA
    .onStart([]() {
      Serial.println("OTA update started. ESP-NOW sending stopped.");
    })
    .onEnd([]() {
      Serial.println("\nOTA update finished.");
    })
    .onProgress([](unsigned int progress, unsigned int total) {
      const unsigned int percent = total == 0 ? 0 : (progress * 100) / total;
      static unsigned int lastPercent = 101;
      if (percent != lastPercent) {
        lastPercent = percent;
        Serial.printf("OTA progress: %u%%\r", percent);
      }
    })
    .onError([](ota_error_t error) {
      Serial.printf("OTA error[%u]\n", error);
    });

  ArduinoOTA.begin();
  otaStarted = true;
  M5.Display.fillScreen(BLUE);
  M5.Display.setCursor(4, 8);
  M5.Display.setTextColor(WHITE, BLUE);
  M5.Display.println("OTA READY");
  M5.Display.println(OTA_HOSTNAME);
  M5.Display.println(WiFi.localIP().toString());
  Serial.printf("OTA ready: %s.local IP: %s\n", OTA_HOSTNAME, WiFi.localIP().toString().c_str());
}

void enableOTAMode()
{
  if (otaModeEnabled) {
    return;
  }

  otaModeEnabled = true;
  esp_now_deinit();
  WiFi.disconnect(false, true);
  lastOtaWifiAttemptMs = 0;
  M5.Display.fillScreen(BLUE);
  M5.Display.setCursor(4, 8);
  M5.Display.setTextColor(WHITE, BLUE);
  M5.Display.println("OTA MODE");
  M5.Display.println("WiFi connecting");
  M5.Display.println(OTA_HOSTNAME);
  Serial.println("OTA mode enabled. Upload by espota.");
}

bool serviceOTAMode()
{
  if (!otaModeEnabled) {
    return false;
  }

  if (!otaIsConfigured()) {
    return true;
  }

  if (WiFi.status() != WL_CONNECTED) {
    const uint32_t now = millis();
    if (lastOtaWifiAttemptMs == 0 || now - lastOtaWifiAttemptMs >= kOtaWifiRetryIntervalMs) {
      lastOtaWifiAttemptMs = now;
      WiFi.mode(WIFI_STA);
      WiFi.begin(WIFI_SSID, WIFI_PASSWORD);
      M5.Display.fillScreen(BLUE);
      M5.Display.setCursor(4, 8);
      M5.Display.setTextColor(WHITE, BLUE);
      M5.Display.println("OTA MODE");
      M5.Display.println("WiFi connecting");
      M5.Display.println(WIFI_SSID);
      Serial.printf("Connecting OTA WiFi: %s\n", WIFI_SSID);
    }
    return true;
  }

  setupOTA();
  ArduinoOTA.handle();
  return true;
}
}  // namespace

void rc_init(void)
{
  // ESP-NOW初期化
  WiFi.mode(WIFI_STA);
  WiFi.disconnect();
  if (esp_now_init() == ESP_OK)
  {
    Serial.println("ESPNow Init Success");
  }
  else
  {
    Serial.println("ESPNow Init Failed");
    ESP.restart();
  }

  memset(&peerInfo, 0, sizeof(peerInfo));
  memcpy(peerInfo.peer_addr, BroadcastAddr, 6);
  peerInfo.channel = CHANNEL;
  peerInfo.encrypt = false;
  while (esp_now_add_peer(&peerInfo) != ESP_OK)
  {
    Serial.println("Failed to add peer");
  }
  esp_wifi_set_channel(CHANNEL, WIFI_SECOND_CHAN_NONE);
}

// 周期カウンタ割り込み関数
hw_timer_t *timer = NULL;
void IRAM_ATTR onTimer()
{
  Loop_flag = 1;
}
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

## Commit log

2025-07-06 初回コミット
2026-06-25 Update README for AtomS3R and wiring details
2026-06-25 Add 3D model files
    [80mm_mecanu_top_cover.step, 80mm_mecanu_top_cover.stl, 80mm_mecanum_hub.step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]
2026-06-25 起動方法追加
2026-06-26 hub修正
    [80mm_mecanum_hub.step, 80mm_mecanum_hub.stl]
2026-06-26 3Dモデル追加
    [NP-F550_batt_case.step, NP-F550_batt_case.stl]
2026-06-26 写真追加
2026-07-03 READMEに動画リンクを追加
2026-09-04 Clarify wiring and fabrication guidance
